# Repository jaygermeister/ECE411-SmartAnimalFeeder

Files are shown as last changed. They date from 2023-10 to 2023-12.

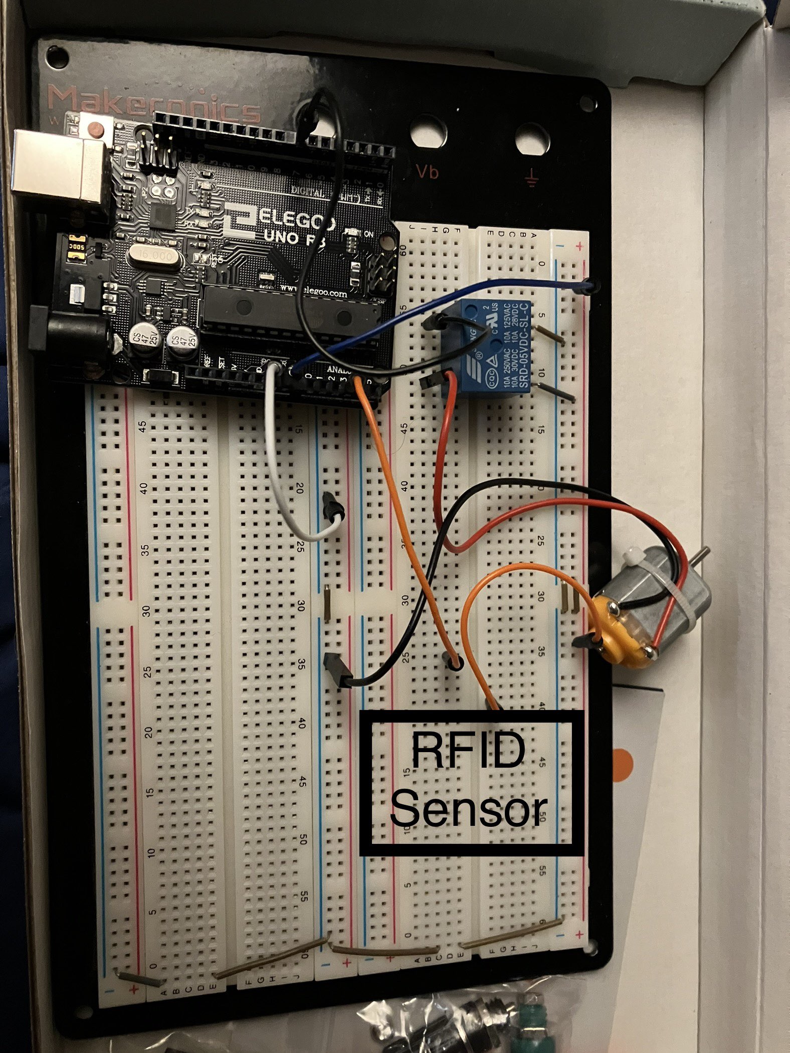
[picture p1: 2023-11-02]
BREADBOARD.jpg

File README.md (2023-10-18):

# ECE411 Smart Animal Feeder

The Smart Animal Feeder is a comprehensive solution that caters to the diverse needs of pets in a household. It brings convenience, efficiency, and peace of mind to pet owners, ensuring that feeding time becomes a harmonious and stress-free experience.

The product will be designed as a team effort for ECE411 of Fall 2023 at Portland State University.

Team 13 is under the instruction of Andrew Greenberg.

## Team Members:
- Isaac Miller
- Brian Bach
- James Best
- Tommy Lee

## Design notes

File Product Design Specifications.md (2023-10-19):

# Executive Summary

The Smart Animal Feeder is a comprehensive solution that caters to the diverse needs of pets in a household. It brings convenience, efficiency, and peace of mind to pet owners, ensuring that feeding time becomes a harmonious and stress-free experience.

The Smart Animal Feeder offers a personalized feeding schedule, allowing users to dispense precise portions of food to prevent overeating or disruptions in feeding routines. This is particularly useful for households with pets that have unique dietary needs, including those requiring special veterinary-prescribed foods or having allergy considerations.

Designed to bring harmony to multi-pet environments, this feeder incorporates an intelligent system that dispenses food exclusively to the designated pet wearing an RF chip on its collar. This feature not only prevents feeding chaos but also ensures that each pet receives the appropriate nutrition without interference from others.

Equipped with a spacious hopper, the feeder can store and maintain the freshness of a week's worth of food. The automatic dispensing mechanism, powered by a motor, eliminates the need for manual feeding, providing a hassle-free and consistent experience for both pets and their owners.

The RF chip on the animal's collar serves as a secure identifier, allowing only the specified pet access to the feeding bowl. In the absence of the chip, the feeder seals the tray, preventing unauthorized access and promoting the security of the feeding process.

# Market Analysis

Target Audience: Pet owners with multiple animals, especially those facing challenges in managing different dietary needs and preventing overeating in a household with multiple pets.

Unique Selling Points:
- Individualized feeding with RF ID technology
- Prevention of feeding chaos in multi-pet environments
- Ease of use for customizable feeding schedules

Competitive Edge:
Distinguished from competitors by offering RF ID individualized feeding for multi-animal homes. Most existing products lack the ability to monitor animals, ensuring the correct pet receives its intended meal.

Price Point:
Competitively priced compared to standard automatic pet feeders, making it accessible to a broad range of pet owners while reflecting the value of its unique features.

# Requirements

Musts:
- Must dispense food 
- Must use RF ID technology

Shoulds:
- Should dispense food at user defined times

Mays:
- May control portion size
- May be controlled remotely
- May notify the user that it's running out of food
- May dispense two or three different foods

# System Architecture
feeder

- **Level 0 Block Diagram:** <br />
  block0

- **Level 1 Block Diagram:** <br />
  block1

# Smart Animal Feeder with RFID - Design Specification

## Technical Details

- **Sensor:**
  - RFID reader for pet identification
  - Infrared or pressure sensors for detecting pet presence near the bowl

- **Processor:**
  - Microcontroller unit (MCU), such as Arduino or other microcontroller with RFID and sensor support

- **Actuator:**
  - Motorized dispenser for releasing pet food
  - Bowl sealing mechanism with controlled movement

- **Power:**
  - DC power supply or battery pack, depending on the intended use and location

- **Mechanical Design:**
  - Hopper or container for storing pet food
  - Dispenser mechanism with a motor to control food release
  - RFID tag reader positioned at the entrance for pet identification
  - Safety shields and barriers to prevent pet access to moving parts

- **Firmware:**
  - Code to control RFID reading, food dispensing, and communication with other components
  - Safety algorithms for controlled bowl sealing and emergency stop

- **Arduino or No Arduino:**
  - The choice depends on the specific requirements; Arduino for simplicity, dedicated microcontroller for more control

- **Development Environment:**
  - Arduino IDE or suitable IDE for the chosen microcontroller
  - RFID library for reading RFID tags
  - Motor control libraries (if using a motorized dispenser)

- **Communication (Optional):**
  - Options like Bluetooth, Wi-Fi, or other wireless protocols for remote monitoring or control

- **User Interface (Optional):**
  - LEDs, buttons, or a small display for basic user interaction
    or 
  - Phone interface over Wifi or other wireless protocol 

## Safety Features

- **Bowl Sealing Mechanism:**
  - Sensors to detect the presence of the pet near the bowl
  - Safety sensor to detect if anything is obstructing sealing mechanism before engaging
  - Emergency stop mechanism for manual or automatic activation in case of malfunction
  - Slow and smooth movement to avoid startling or harming the pet
  - Physical barriers/shields to prevent pet access to moving parts

These safety features aim to ensure the well-being of the pet and enhance the overall reliability of the smart animal feeder.

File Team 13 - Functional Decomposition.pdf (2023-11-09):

# RFID Reader: Level 0

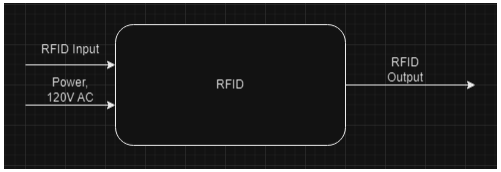
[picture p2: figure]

Module | RFID
Inputs | RFID input Power: 120V AC, 60Hz
Outputs | RFID output
Function | To recognize the RFID tags which is put on the pet, so the feeder only feed the tagged one.

# RFID Reader: Level 1

# RFID Antenna: Level 1

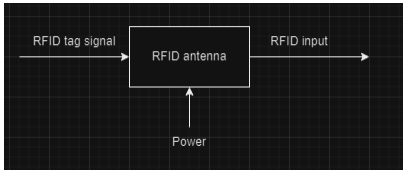
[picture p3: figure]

Module | RFID antenna
Inputs | RFID tag signal Power: 12V 2A
Outputs | RFID input
Function | The RFID antenna finds the signal from the RFID tags then provide the RFID input for the reader.

# RFID reader: Level 1

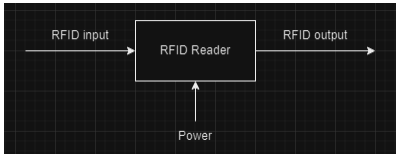
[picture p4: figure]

Module | RFID Reader
Inputs | RFID input Power: 12V 2A
Outputs | RFID output
Function | The RFID reader will get the RFID input from the RFID antenna then provide the RFID output to the processor.

# Power Supply: Level 1

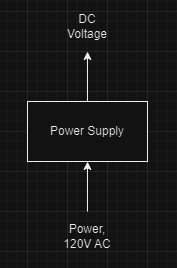
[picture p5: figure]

Module | Power Supply
Inputs | Power: 120V AC
Outputs | Power DC
Function | Convert AC wall outlet voltage to DC output voltages.

# Motor Controller: Level 0

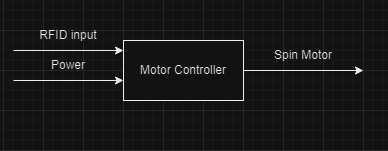
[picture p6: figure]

Module | Motor Controller
Inputs | RFID Input Power: 12V 2A
Outputs | Spin Motor
Function | Receive RFID input from RFID reader then send signal to the motor controller, which will send command to spin the motor.

# Motor Controller: Level 1

# Motor Controller: Level 1

Module | Motor Controller
Inputs | RFID Input Power: 12V 2A
Outputs | Motor Command
Function | Receive RFID input from RFID reader then send command to the DC motor.

# Motor: Level 1

Module | Motor
Inputs | Motor Command Power: 12V 2A
Outputs | Spin DC Motor
Function | Receive Motor Command from Motor Controller then spin when received command.

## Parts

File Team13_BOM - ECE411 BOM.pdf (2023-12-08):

Bill Of Materials for: [Team 13] [Smart Animal Feeder]
Last modified: [05 December 2023]
PCB version: [PCB VERSION #2]
BOM revision: [BOM REVISION #2] | P/NP = Place/Not Place (components marked NP are not stuffed on the board)
Cnt | Part References | P/NP Mfg | Mfg PN | Description | Dist | Dist Part Number | Cost Ea. | Cost Total
1 NA | NP | Zevro | KCH-06114 | Food Dispenser Single Control | Amazon | B00013K8O4 | $17.72 | $17.72
1 RFID1 | P/NP Smooth Technology | 5402 | RFID Kit with multiple contents inside | Adafruit | 5402 | $49.95 | $49.95
1 M1 | NP | Toshiba | TA8080K | TA8080K Motor Driver With Brake Function | Applied Motion Products Inc. | 4023-820 | $9.99 | $9.99
1 A1 | NP | Elegoo | EL-CB-001 | Arduino UNO R3 Board | Elegoo | EL-CB-001 | $18.00 | $18.00
1 U1 | NP | Qunqi | MK-050 | H Bridge Driver for DC Stepper For Arduino | Amazon | CECOMINOD012186 | $6.99 | $6.99
3 | R1, R2, R3 | P | Yageo | CFR200J1K0 | 0 Ohms resistors | Digikey | 13-CFR-25-T-52-0RCT-ND | $0.10 | $0.30
8 | NA | P | Z&T Store | WSJ-100 | Jumper Wires | Amazon | B005TZJ0AM | $0.11 | $0.88
1 | J1 | P | CUI Devices | PJ-102AH | Barell Jack | Digikey | CP-102AH-ND | $0.70 | $0.70
1 | NA | NP | NA | NA | Wood board for the base of the project | NA | NA | $0.00 | $0.00
1 | NA | NP | M-D Building Products | 56032 | Sheet of metal for the ramp for the food | Home Depot | 1001195220 | $10.47 | $10.47
1 | NA | NP | OSHPark | NA | Main PCB Board | OSHPark | NA | $26.67 | $26.67
| | | | | | | | TOTAL: | $141.67

VERSION INFO

Rev | Date | Notes
1.0r2 2023-12-05 | Adding more parts that was needed when putting them together
1.0r1 2023-11-08 | Cleaned up parts, rough draft of board
1.0r0 2023-11-05 | Initial BOM

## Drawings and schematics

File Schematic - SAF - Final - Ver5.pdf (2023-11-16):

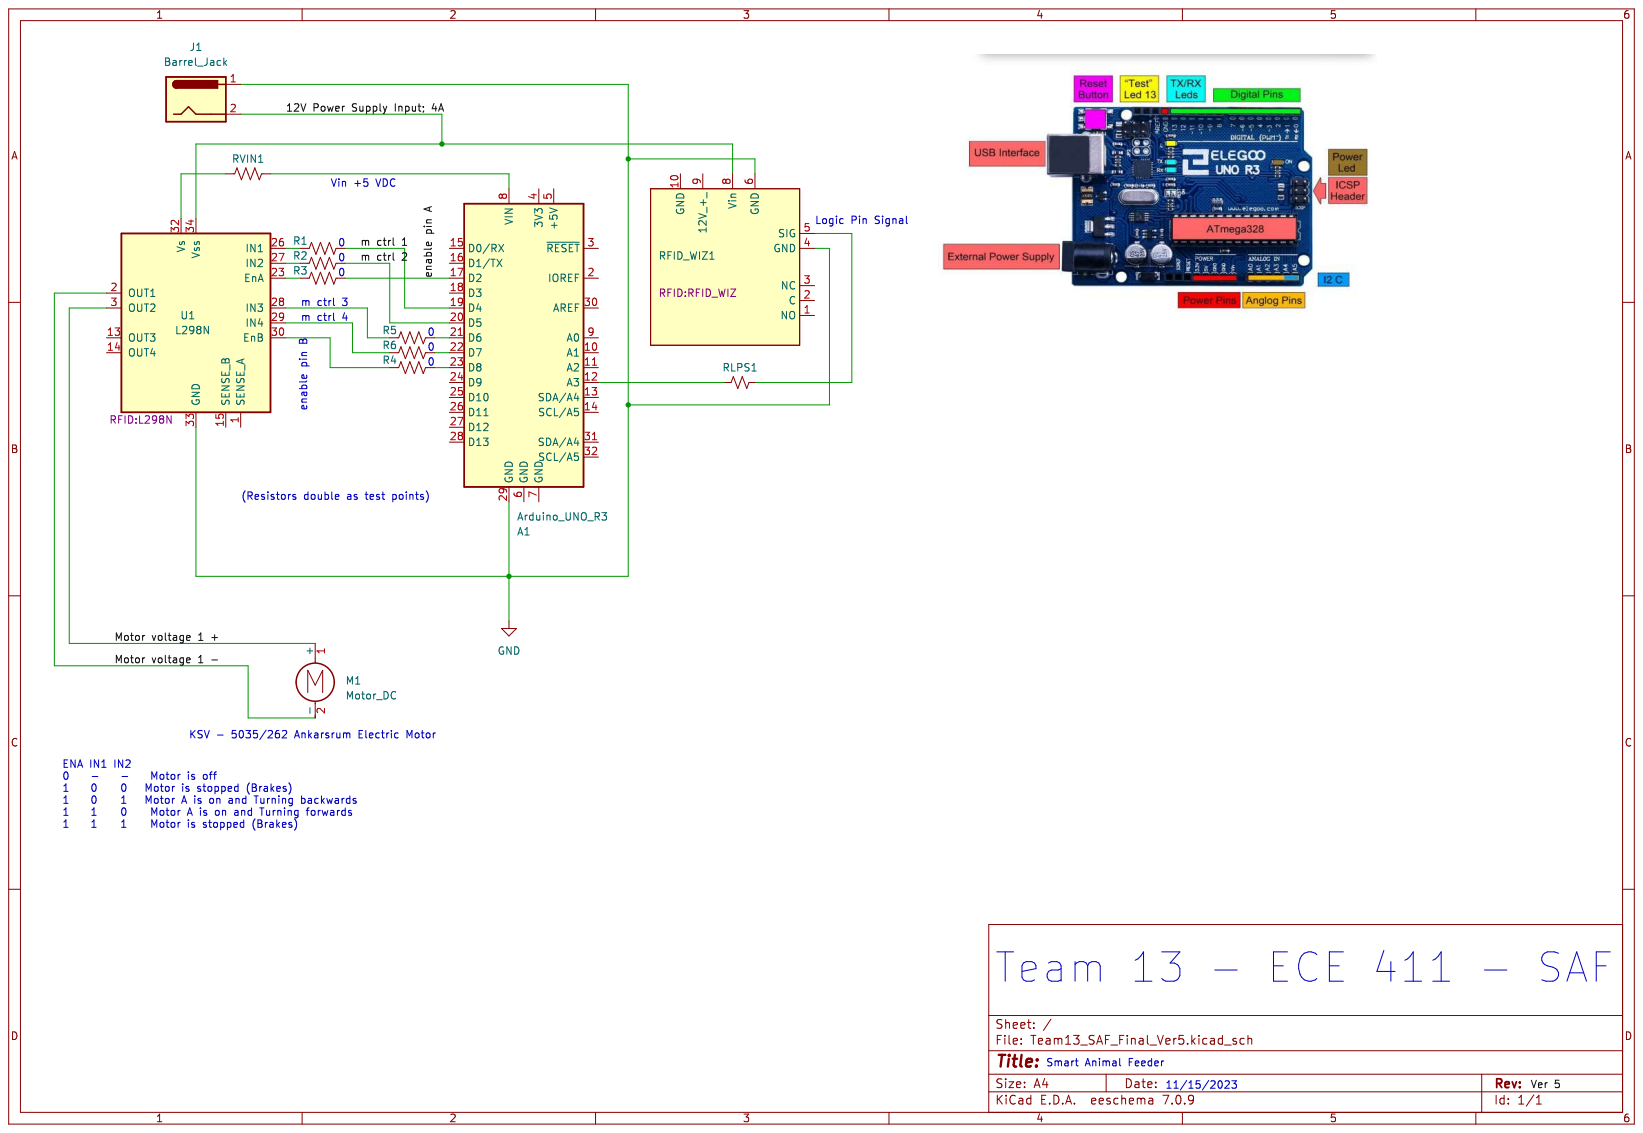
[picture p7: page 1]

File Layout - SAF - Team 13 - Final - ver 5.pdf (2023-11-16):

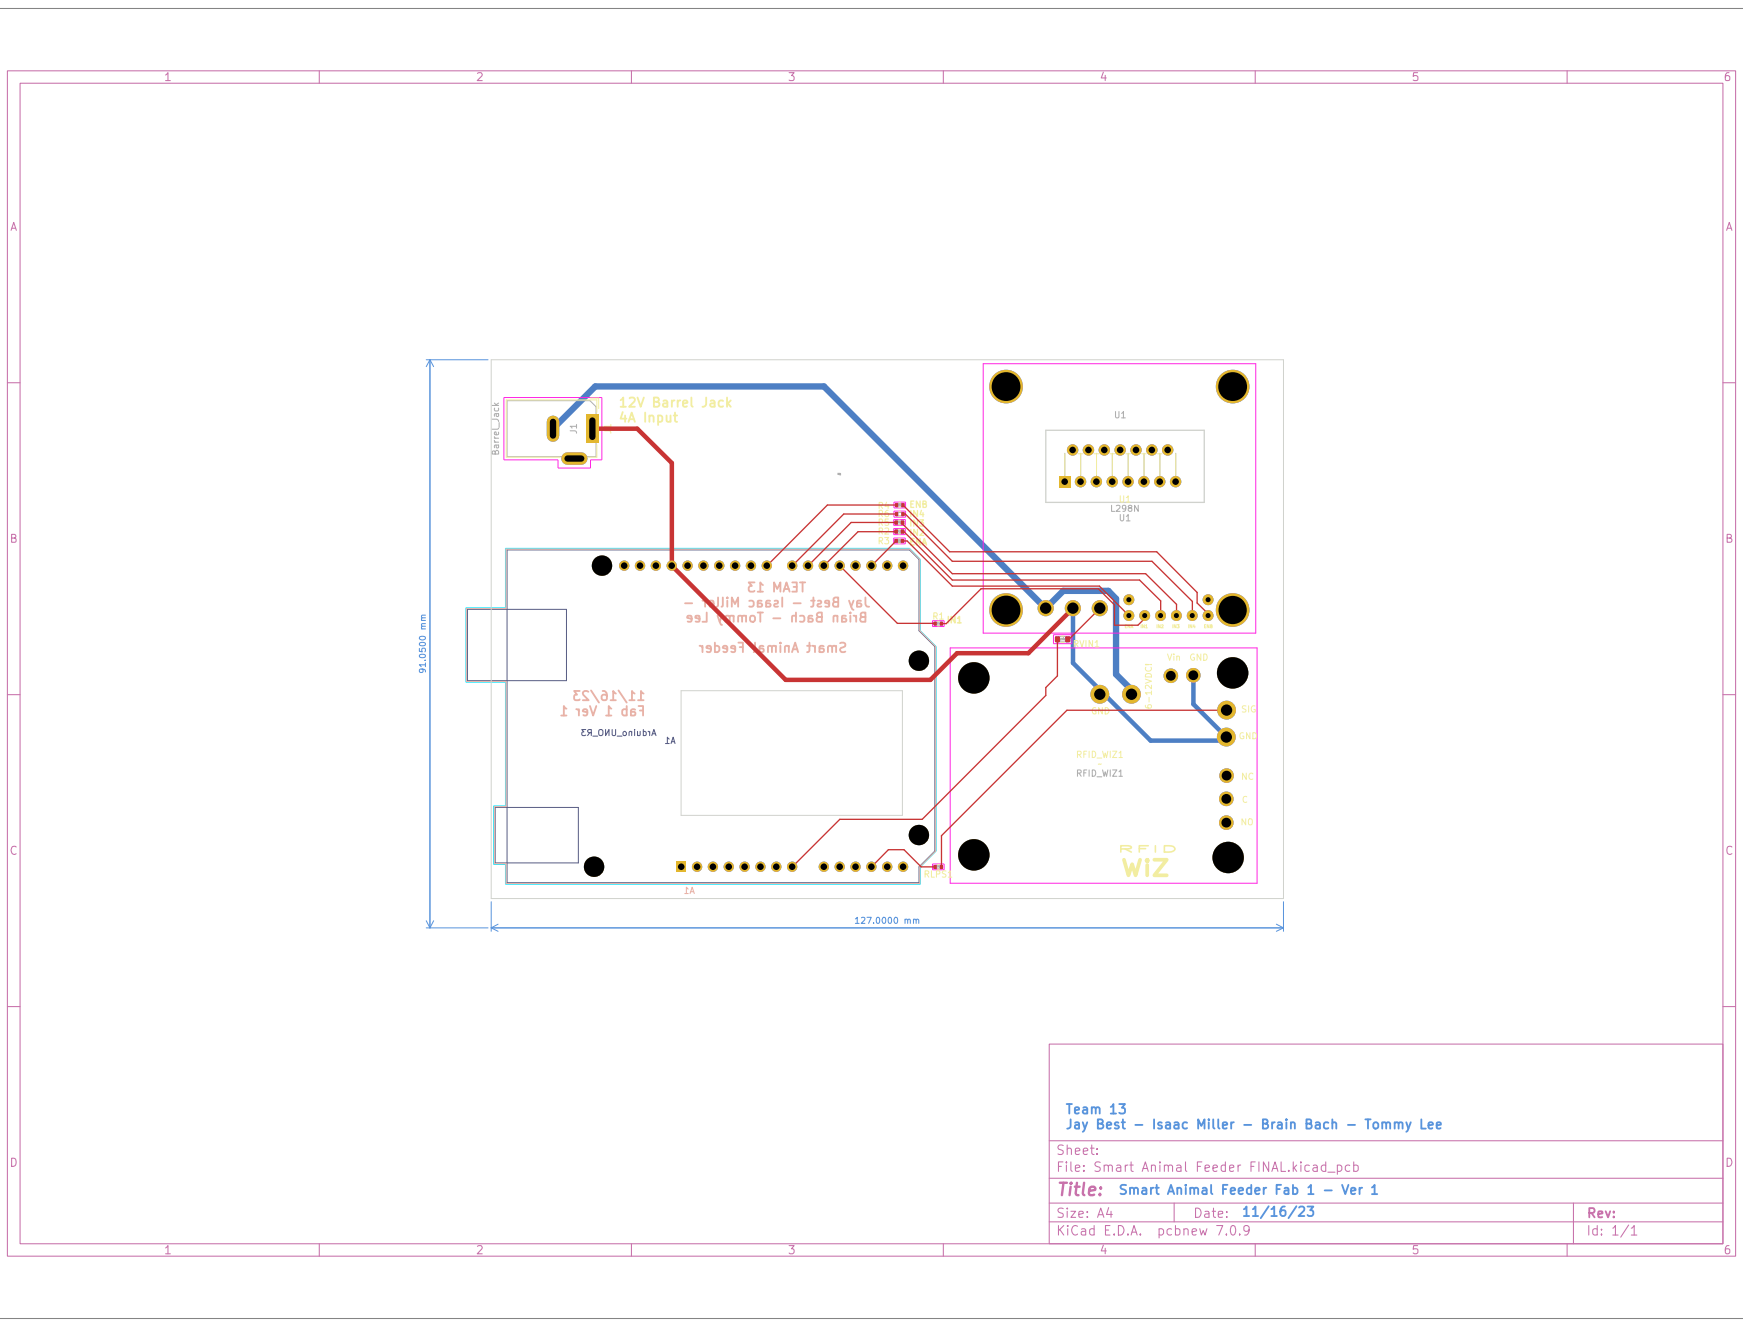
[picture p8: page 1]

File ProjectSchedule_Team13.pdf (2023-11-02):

# 1. Task Sheet

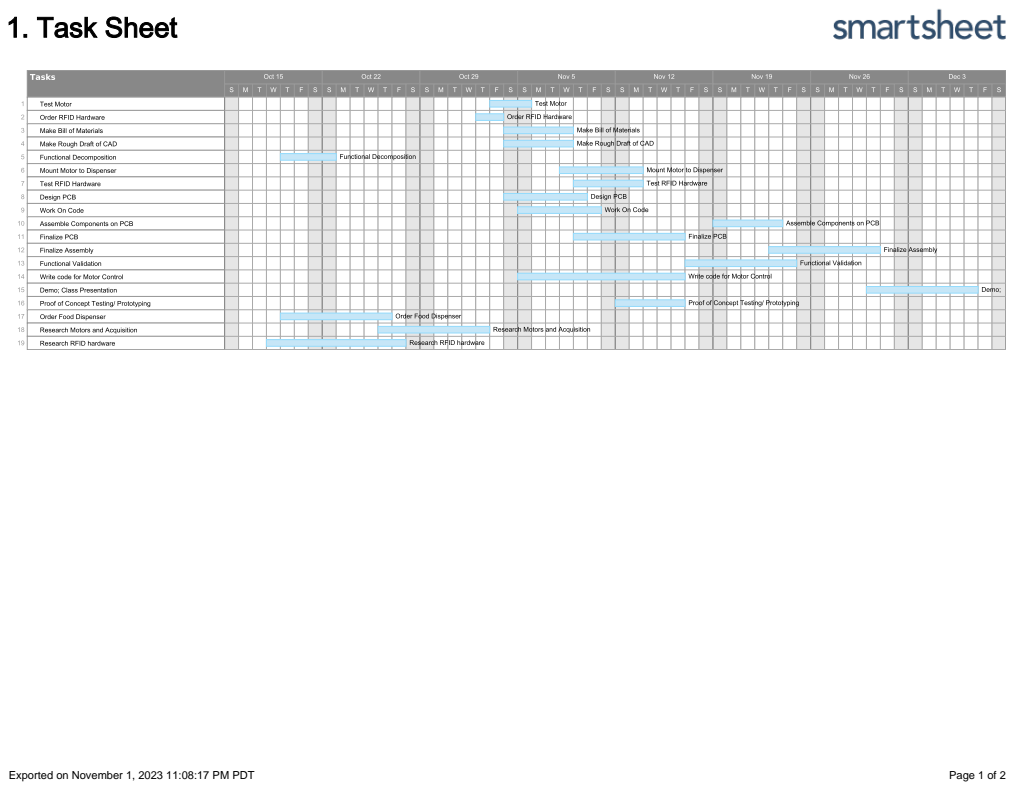
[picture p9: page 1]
Exported on November 1, 2023 11:08:17 PM PDT; Page 1 of

Brian Bach (bach3@pdx.edu) | November 1, 2023 10:28 PM
https://www.adafruit.com/product/5402

## Comments

Row 2

Exported on November 1, 2023 11:08:17 PM PDT | Page 2 of

2

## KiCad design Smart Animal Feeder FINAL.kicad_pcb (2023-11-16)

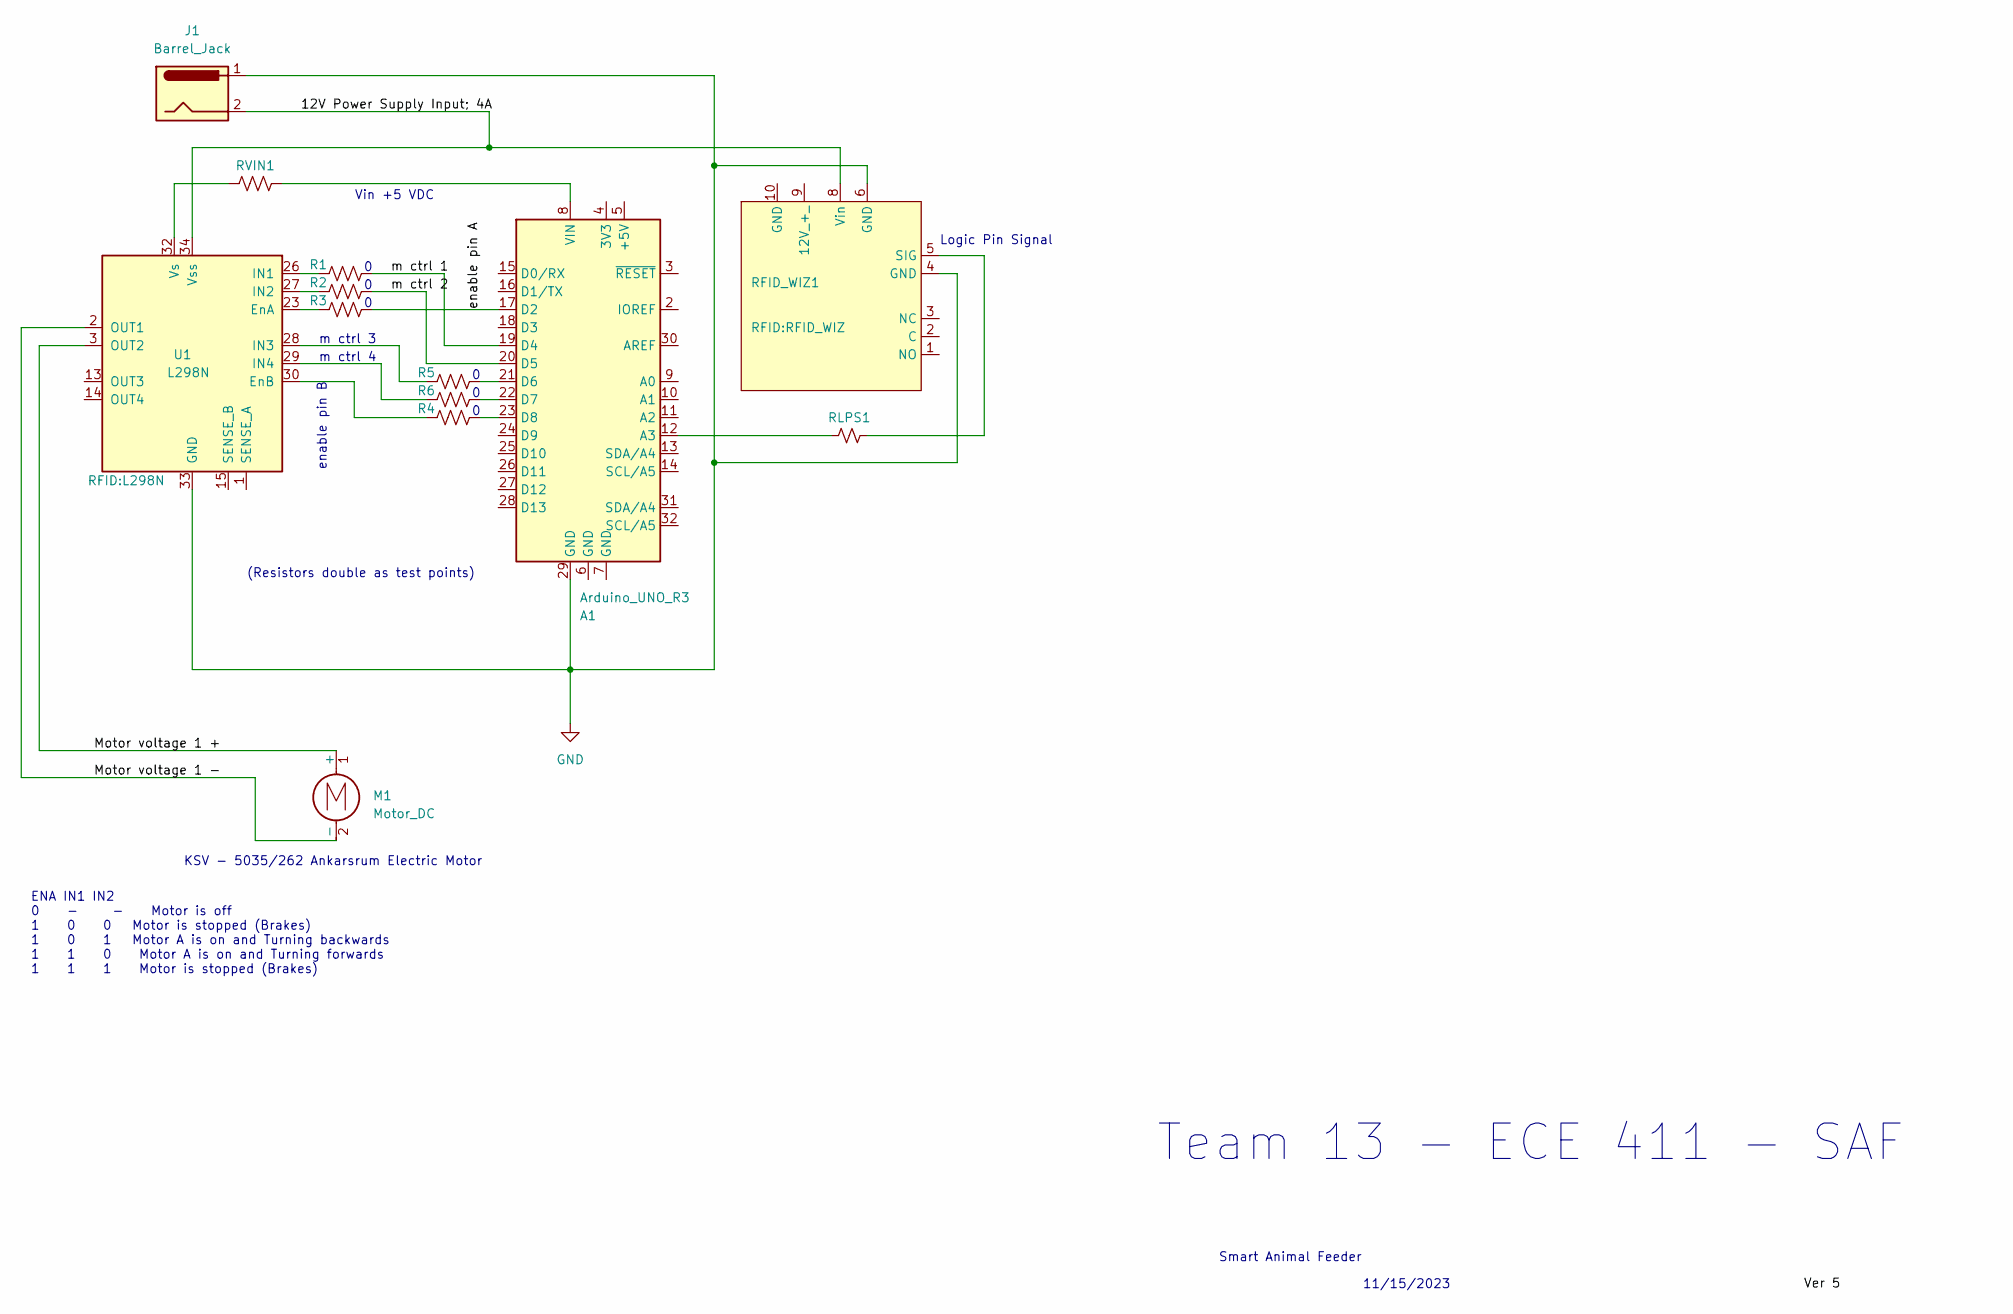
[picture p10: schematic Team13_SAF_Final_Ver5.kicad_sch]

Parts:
A1: Arduino_UNO_R3; Arduino_UNO_R3_WithMountingHoles
J1: Barrel_Jack; BarrelJack_GCT_DCJ200-10-A_Horizontal
M1: Motor_DC
R1, R2, R3, R4, R5, R6: R_US; R_0402_1005Metric
RFID_WIZ1: RFID_WIZ
RLPS1: R_Small_US; R_0402_1005Metric
RVIN1: R_US; R_0603_1608Metric
U1: L298N

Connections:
/12V Power Supply Input; 4A: J1.2, RFID_WIZ1.8 (Vin), U1.34 (Vss)
/Motor voltage 1 +: M1.1 (+), U1.3 (OUT2)
/Motor voltage 1 -: M1.2 (-), U1.2 (OUT1)
/Motor voltage 2 +: U1.14 (OUT4)
/Motor voltage 2 -: U1.13 (OUT3)
/enable pin A: A1.17 (D2), R3.1
/m ctrl 1: A1.19 (D4), R1.1
/m ctrl 2: A1.20 (D5), R2.1
GND: A1.29 (GND), J1.1, RFID_WIZ1.4 (GND), RFID_WIZ1.6 (GND), RFID_WIZ1.9 (12V_+_), U1.33 (GND)
unnamed: A1.12 (A3), RLPS1.2
unnamed: A1.21 (D6), R5.1
unnamed: A1.22 (D7), R6.1
unnamed: A1.23 (D8), R4.1
unnamed: A1.8 (VIN), RVIN1.1
unnamed: RFID_WIZ1.5 (SIG), RLPS1.1
unnamed: R3.2, U1.23 (EnA)
unnamed: R4.2, U1.30 (EnB)
unnamed: R1.2, U1.26 (IN1)
unnamed: R2.2, U1.27 (IN2)
unnamed: R5.2, U1.28 (IN3)
unnamed: R6.2, U1.29 (IN4)
unnamed: RVIN1.2, U1.32 (Vs)

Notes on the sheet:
(Resistors double as test points)
m ctrl 3
Logic Pin Signal
Smart Animal Feeder
KSV - 5035/262 Ankarsrum Electric Motor
Vin +5 VDC
enable pin B
ENA IN1 IN2 0 - - Motor is off 1 0 0 Motor is stopped (Brakes) 1 0 1 Motor A is on and Turning backwards 1 1 0 Motor A is on and Turning forwards 1 1 1 Motor is stopped (Brakes)
11/15/2023
Team 13 - ECE 411 - SAF
m ctrl 4

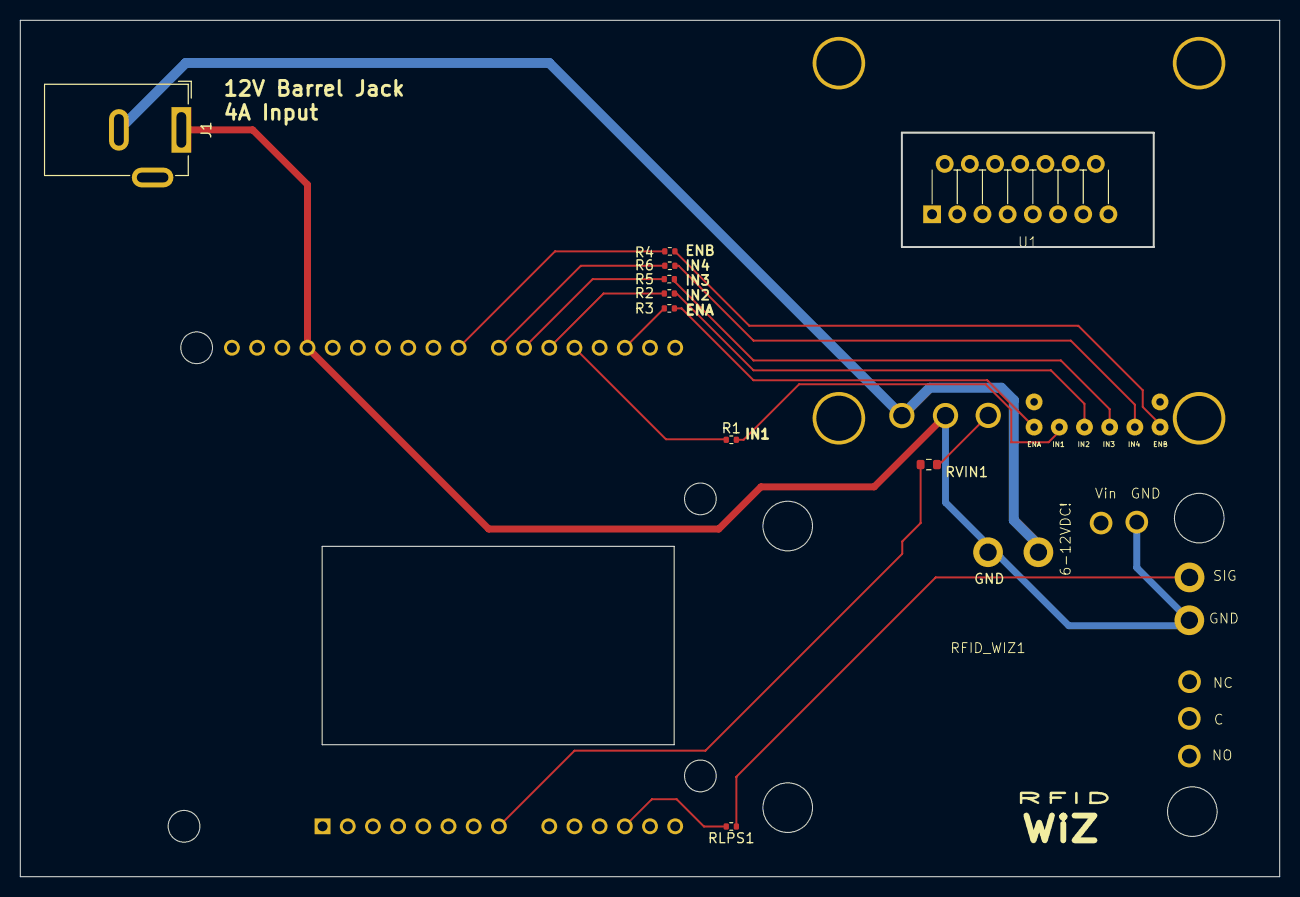
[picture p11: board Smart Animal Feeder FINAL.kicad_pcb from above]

Board: 2 copper layers, 127.0 x 86.4 mm, 12 parts (1 on the bottom side), 18 nets.

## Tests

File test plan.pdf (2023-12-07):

Test Author: Group 13
Test Case Name: | Motor speed test | Test ID #: | AF-Mot-01
Description: | Test the speed and strength of the motor | Type: | □ white box ☑ black box □ ________

Tester Information
| Name of Tester: | Jay Best | Date: | 30/11/2023
| HW/SW Version: | 1.0 | Time: | 3PM
| Setup: | Attach motor to adjustable DC power supply. Range 10V -24VDC and Current 1A-4A
S T E P | Action | Expected Result | P A S S | F A I L | N / A | Comments
1 | Test motor at 1A (12V) | Motor should spin very slowly | x
2 | Test motor at 2A (12V) | Motor should spin more rapidly | x | | | This is what healthy driver expected to provide to motor
3 | Test motor at 70% power (9V) | Motor should spin weakly | X
4 | Test motor at 80% power (10V) | Motor should spin strong | x | | | This is acceptable for functionality
5 | Test motor at 100% power(12V) | Motor should spin strongly | x | | | This is acceptable for functionality

6
7
8 | Notes: | Motor is rated for current up to 4 A. Motor speed is current dependent. 2A is nominal running current.

9
| Overall test result: | | 2 | 3

Test Case Name: | RFID tag reader test | Test ID #: | RFID-01
Description: | Evaluate the RFID tag reader abilities. This involves verifying the reader’s reading range, and its ability to recognize the correct tag. | Type: | □ white box ☑ black box □ _____________

Tester Information

| Name of Tester: | Brian | Date: | 4 November 2023
| HW/SW Version: | 1.0 | Time: | 1:00 PM
| Setup: | Make sure that the RFID reader was set up correctly and it is functionable.
T ES T | Action | EXPECTED Results | P A S S | F A I L | N / A | Comments
1 | Move the RFID tag slowly toward the RFID reader. | RFID reader should be triggered and make the power relay to be activate | x | | | When a tag is detected, the motor will spin.
2 | Tried different RFID tags | RFID reader only triggered with the correct tag | x | | | Tags are programmable and readers can be trained per tag.

3

4 | | | 2

Overall test result:

Test Author: Group 13
Test Case Name: | Motor Driver Test | Test ID #: | C.A.T.-01
Description: | Testing the Truth table and logic for driving the motor | Type: | □ white box ☑ black box □ ________

Tester Information
| Name of Tester: | Jay Best | Date: | 30/11/2023
| HW/SW Version: | L298N | Time: | 3PM
| Setup: | Connect Arduino programmed with multiple states to test driver functionality. Output B is used for Motor
S T E P | Action | Expected Result | P A S S | F A I L | N / A | Comments
1 | EnB:1, IN3:0, IN4:1 | Motor should be on and rotating backwards | X | | | Motor turns backwards
2 | EnB:0, N/A, N/A | Motor should not engage with ENB pin set low | X | | | Motor does not engage
3 | EnB:1, IN3:0, IN4:0 | Motor should be in off state (brake) | X | | | Motor is stopped
4 | ENB:1, IN3:1, IN4:0 | Motor should be on and rotating forwards | X | | | Motor turns forwards
5 | ENB:1, IN3:1, IN4:1 | Motor should be in off state (brake) | X | | | Motor is stopped
6
7
8
9
| Overall test result: | | 5

Test Author: Group 13
Test Case Name: | Motor Dispenser Combination test | Test ID #: | C.A.T.-01
Description: | Test the motors ability to dispense food with a loaded hopper | Type: | □ white box ☑ black box □ ________

Tester Information
| Name of Tester: | Isaac | Date: | 4 November 2023
| HW/SW Version: | Alpha 1.3 | Time: | 3PM
| Setup: | Assembled product with food in the hopper.
S T E P | Action | Expected Result | P A S S | F A I L | N / A | Comments
1 | Test motor with 0 cups of food | Motor should turn spindle and spin freely without binding | X
2 | Test motor with 1 cups of food | Motor should turn spindle and dispense food onto shute | X
3 | Test motor with 2 cups of food | Motor should turn spindle and dispense food onto shute | X
4 | Test motor with 3 cups of food | Motor should turn spindle and dispense food onto shute | X
5 | Test motor with 4 cups of food | Motor should turn spindle and dispense food onto shute | X
6 | Test motor with 5 cups of food | Motor should turn spindle and dispense food onto shute | X
7
8
9
| Overall test result: | | 6

Unit Test

Module | Digital Compass – Geosensor version 2.3
Inputs | - | Earth’s magnetic field: An orientated field of magnetic force beginning and ending at the earth’s magnetic poles.
- SClk – Clock signal to clock data through the module.
| | Maximum Frequency is 10Mhz.

## - SDIn – Serial data input to send data into the compass

| | module. Date is valid on positive SClk edges.
Outputs | - | SDOut – Serial data output from the compass module. Data is valid on negative clock edges.
Functionality | Senses the earth’s magnetic field and determines the

## orientation of the compass with respect to the field. This orientation is stored in an internal register and can be

retrieved through the SPI interface.
Test | Comp-UT-01

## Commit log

2023-10-12 Update README.md
    Create a collaboration site for your team. The collaboration site must:
    Have version (“revision”) control
    Support collaborative documentation (e.g., markdown files, wiki, HTML pages)
    Have some kind of issue tracking
    For example, a freely available Github site matches all of these requirements, which is what we'll officially support in ECE411. Your repository can be public (don’t forget to choose a license!) or it can be private (even so, don’t forget to choose a license!). Please don't start a github organization, that's unnecessarily complicated. Just create a new repository and share it with your team mates. Also, please name it something descriptive - ECE41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
2023-10-26 Add files via upload
    Preliminary detailed schematic
2023-11-02 Updated Schematic 1 - SAF - Team 13-pdf.jpg
    The new and improved schematic
2023-11-02 Add files via upload
    Updated Schematic
2023-11-09 Add files via upload
    Schematic version 2. The motor has been selected and the driver selection updated.
    Signal labels were added and logic table will be added next revision.
2023-11-09 Add files via upload
    PCB 1st draft. Routing needs attention and finalized
    Need to create power delivery with appropriate traces for current and voltage ratings and routing to subsystems
    [Smart Animal Feeder version 2.kicad_pcb]
2023-11-09 Add files via upload
    PCB version of 1st draft CAD brd file
2023-11-11 Add files via upload
    Revised Schematic for parts. Added power lines and descriptions. Included truth table for motor control from Microcontroller.
2023-11-13 Add files via upload
    Semi Final PCB design for team review.
    Added mounting holes for individual modules
    trace routing for all signals
    PCB cutouts for module pin clearance for existing solder work
    Routing for 12V power Delivery
    Routing for 5-7V from L298N to Supply power to Arduino
    Added zero ohm resistors for test points and branch options
    Silk screen Refdes annotations
    Team members silk screen on back side
    [Team13_SAF_SemiFinal_Ver4.kicad_pcb]
2023-11-13 Semi Final draft of Schematic for Review
    [Team13_SAF_SemiFinal_Ver4.kicad_sch]
2023-11-14 PDF of layout file
    Printer ready version of the PCB layout for SAF. Needs final review this week (11/14)
2023-11-14 Schematic PDF for review
2023-11-16 uploading Wk 08 files
    Adding pdf schematic final version
    adding pdf of layout final version
    attaching kicad sketch files to preserve on cloud
    [Smart Animal Feeder FINAL.kicad_pcb, Team13_SAF_Final_Ver5.kicad_sch]
2023-12-04 Create Arduino_Code
    This is the bare minimum code for the arduino to collect the signal state from the RFID WIZ and determine if the motor should be turned.
2023-12-04 Delete Schematic - SAF - SemiFinal - Ver4.pdf
    cleaning up earlier revs
2023-12-04 Delete Schematic 1 - SAF - Team 13 Version 2.pdf
    cleaning up obsolete revision numbers
2023-12-04 Delete Schematic 1 - SAF - Team 13 Version 3.pdf
    cleaning up obsolete files
2023-12-04 Delete Schematic 1 - SAF - Team 13.pdf
    deleting obsolete revisions
2023-12-04 Delete Smart Animal Feeder version 2.kicad_pcb
    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
    [Smart Animal Feeder version 2.kicad_pcb]
2023-12-04 Delete Team 13 - CAD 1 - PCB.pdf
    deleting obsolete files
2023-12-04 Delete Team13_SAF_SemiFinal_Ver4.kicad_pcb
    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
    [Team13_SAF_SemiFinal_Ver4.kicad_pcb]
2023-12-04 Cleaning up Obsolete Files
    Version updated to Alpha Test phase
    [Team13_SAF_SemiFinal_Ver4.kicad_sch]
2023-12-08 Update Arduino_Code
    Added early form of time scheduling, commented out. No actual changes to runnable code.
